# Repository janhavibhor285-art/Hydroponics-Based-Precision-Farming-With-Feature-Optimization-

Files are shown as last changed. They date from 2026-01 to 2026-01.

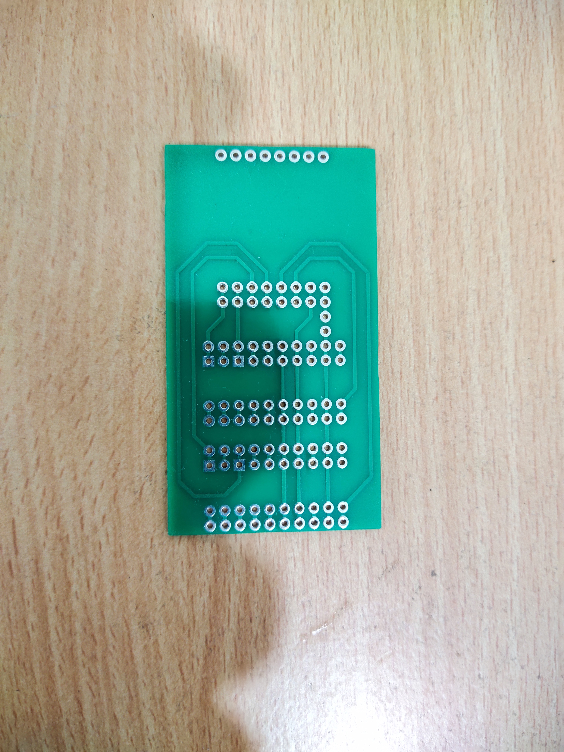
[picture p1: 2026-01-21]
2. Hardware-20260121T212549Z-1-001/2. Hardware/6. Actuator Module Final/7. Actuator Module Development/4. PCB Manufacturing Back.jpg

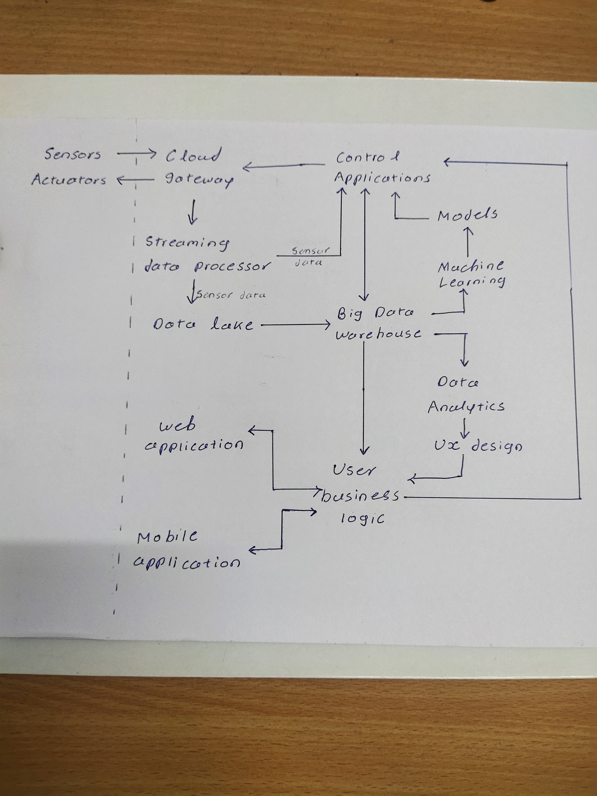
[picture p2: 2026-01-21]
8. Documentations-20260121T212609Z-1-001/8. Documentations/8. Extra Works/rough whole project architecture diagram.jpg

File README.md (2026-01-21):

# Hydroponics-Based-Precision-Farming-With-Feature-Optimization-
Author: Janhavi Bhor
Date: 22 January 2025

# Project Overview
Developed a scalable indoor hydroponics automation system with global monitoring and controllable components. Achieved 90% water savings, 51.6% power reduction, and reduced hardware costs from 1180 to 331. Operated on less than 10W, leading the project from requirement analysis to final testing.

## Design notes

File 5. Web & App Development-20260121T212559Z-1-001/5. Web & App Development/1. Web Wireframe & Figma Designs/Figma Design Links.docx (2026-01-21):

Button Design Link:

https://www.figma.com/file/rlIcAuAG75rzXwAZrkmFJh/BUTTON-DESIGN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

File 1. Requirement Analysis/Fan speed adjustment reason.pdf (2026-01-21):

Project OMEGA | @Varad Chaskar

Why adjust the fan speed instead of simply turning it ON and OFF?

Short answer: To save the power consumption

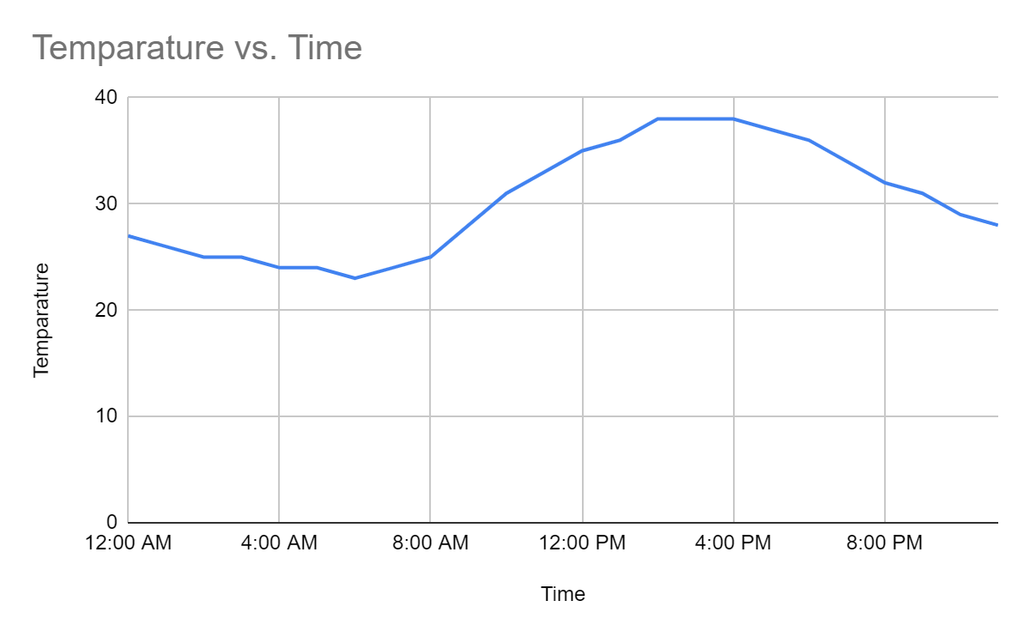
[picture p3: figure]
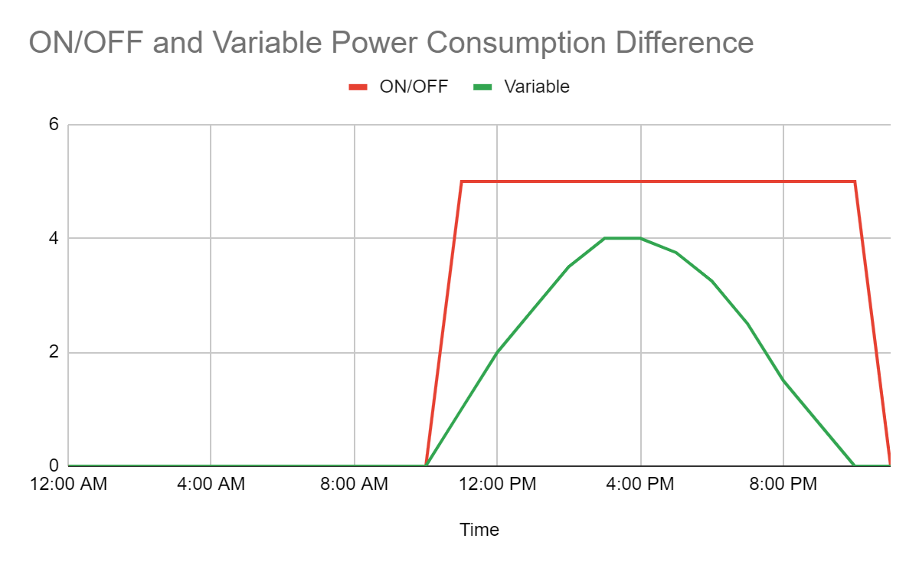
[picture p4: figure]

Assumed that the fan is taking 5V and 1A maximum current at full speed.
In the above temperature scenario, the fan remained ON for 12 Hours.
The total power consumed in ON/OFF conditions for a day in the above scenario: 60 W
The total power consumed in variable speed for a day in the above scenario: 29 W
Thus, we have saved 51.6% of the power by adjusting the fan speed according to the temperature instead of just turning it ON/OFF.

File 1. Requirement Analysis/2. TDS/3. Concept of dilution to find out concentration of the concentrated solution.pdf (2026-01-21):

### 6 ml of X ppm TDS in 1 L of water to achieve TDS of 700-800 ppm

We can use the concept of dilution. The formula for dilution is:

C1 V1 = C2 V2

Where:
C1 = initial concentration of the solution (TDS of X ppm solution)
V1 = initial volume of the solution (6 ml)
C2 = final concentration of the solution after dilution (TDS of 700-800 ppm) V2 = final volume of the solution after dilution (1 L = 1000 ml)

We want to find the initial concentration C1 (TDS of X ppm solution).

Given:
V1 = 6 ml
C2 = 750 ppm (taking an average of the range 700-800 ppm)
V2 = 1000 ml

Using the dilution formula:

C1 x V1 = C2 x V2

C1 x 6 = 750 x 1000

C1 = (750 x 1000) / 6

C1 = 125000

So, the initial concentration C1, or the TDS of the X ppm solution, is 125000 ppm.

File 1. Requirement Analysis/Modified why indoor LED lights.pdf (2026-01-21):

Project OMEGA | @Varad Chaskar

Why indoor hydroponics with LED lights rather than traditional farming?

Short answer: Because we can stack the system with LED lights and earn more profit after some years, below are the approximate cost calculations.
- Land size assumed in all comparisons: 2x1 feet
- Research on: Spinach
- The average no. of days spinach can be cultivated in a year in traditional farming: 243 (In traditional farming pests and heavy rain affect the production)
- Total number of days spinach can be cultivated in a year for hydroponics: 365
- Initial Investment in outdoor hydroponics: 3600 Rs. (Controlled Environment)
- Here, outdoor hydroponics is assumed to grow in the sunlight hence, we can’t stack it.
- Initial investment in indoor hydroponics: 6800 Rs. (2 stacks) (CE) (LED)
- One bunch of spinach can be harvested in an average of 15 days. (250-300 grams)
- Assumed cost of 1 bunch of spinach: 30 Rs.

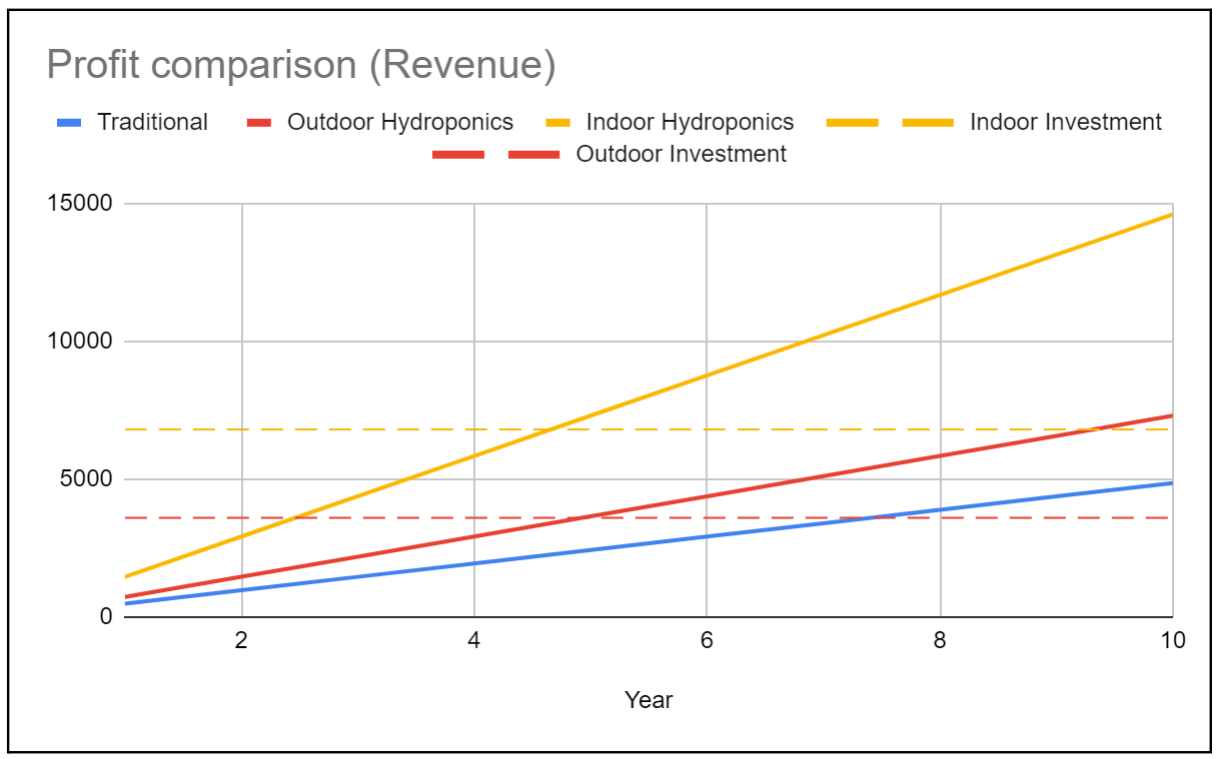
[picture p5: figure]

- Calculated total revenue of traditional farming in the year: 486 Rs.
- Calculated total revenue of outdoor hydroponics system in the year: 730 Rs.
- Calculated total revenue of indoor farming system in the year: 1460 Rs. (2 stacks)
- Years taken to be profitable in both hydroponics systems: 4.5+ Years.
- The total calculated revenue in 2x1 feet 2 stacks indoor hydroponics farming in 10 years is 14,600 Rs. and for outdoor hydroponics is 7,300 Rs.
- Note: Fertilizer cost is assumed to be the same in all methods. and the cost of pesticides in traditional farming is assumed to be the same as the electricity cost in hydroponics hence, they have not been taken into account.

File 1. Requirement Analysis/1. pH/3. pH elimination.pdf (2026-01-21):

pH elimination: using a fixed amount of nutrients with certain pH and 1 L of water.

we have 5 ml of a solute, and we want to mix it with 1 L of water with a pH of 7.0, so that the resulting pH is approximately 6.0.

We can approach this problem using the concept of dilution and the relationship between pH and the concentration of hydrogen ions ([H+]).

For dilute solutions, the pH can be approximated using the equation:

pH = -log10([H+])

Initially, the pH of the water is 7.0, which corresponds to a [H+] of 10^-7 moles/L. we want to mix in 5 ml of a solute, so the final volume becomes 1 L + 0.005 L = 1.005 L.

Let's assume the solute has an initial pH of x. After mixing, the moles of [H+] from the solute and the water must balance out to achieve a pH of 6.0:

([H+] from solute) + ([H+] from water) = Total [H+] after mixing

Using the dilution equation (C1V1 = C2V2), where C is concentration and V is volume, the [H+] from the water remains the same (10^-7), and the [H+] from the solute is given by 10^-x (since the pH of the solute is x).

So the equation becomes:

10^-x + 10^-7 = 10^-6

Solving for x:

10^-x = 10^-6 - 10^-7

x = -log10(10^-6 - 10^-7)

x ≈ 5.301

Therefore, the pH of the solute should be approximately 5.301 to achieve a resulting pH of around 6.0 after mixing it with 1 L of water with a pH of 7.0.

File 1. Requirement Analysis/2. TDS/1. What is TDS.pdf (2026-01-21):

## What is TDS? Its Importance and Maintenance in

Hydroponics.
07.05.23 11:18 PM 0 Comment(s) (https://www.citygreens.in/blogs/post/tds-and-its-importance-in-hydroponics.#comments) By City Greens (https://www.citygreens.in/blogs/author/sales-citygreens.in)

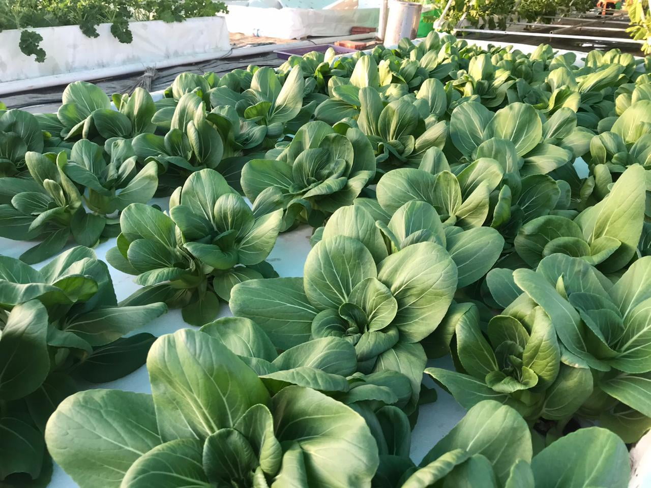
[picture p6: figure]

What is TDS?

TDS stands for Total Dissolved Solids. It is the total amount of inorganic and organic substances dissolved in water or other liquids. These dissolved substances can include minerals, salts, metals, etc. TDS is typically measured in parts per million (ppm) and is an important parameter for assessing water quality.

Why is TDS so important in hydroponics?

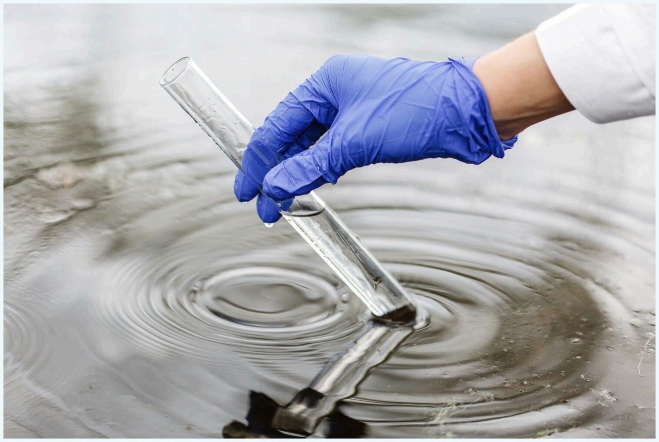
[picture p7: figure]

Water Quality Indicator

A higher TDS reading indicates a higher concentration of dissolved salts and minerals, while a lower TDS reading indicates a lower concentration.

If the raw water TDS is high it can lead to nutrient locking, which can result in poor growth and nutrient deficiencies in plants. Also, the higher the TDS, the higher the chances of the presence of harmful elements or chemicals. So it is advisable to use RO water with a lesser TDS for more control over the nutrition you provide for your plants. It is advisable to use water with a TDS of less than 250 ppm. The lower the better.

TDS Tolerance

TDS requirements for every plant are different from others. For example, lettuces and exotics need a tds range of 700-800 ppm, while tomatoes can tolerate a tds of 2100 ppm.

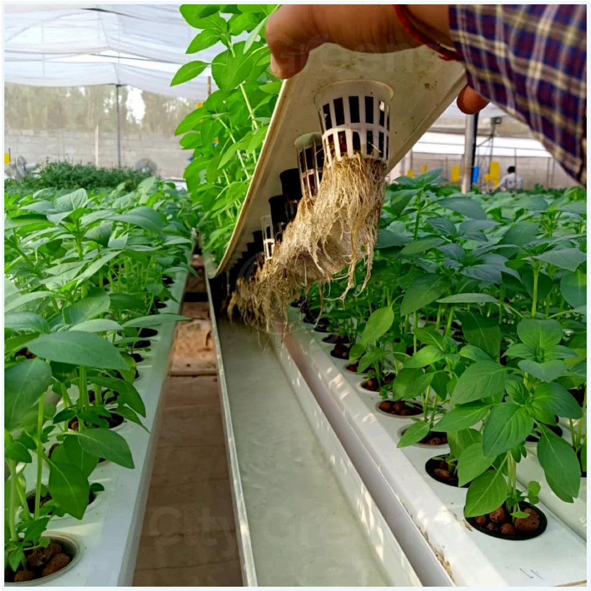
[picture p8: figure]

You can never treat lettuces and tomatoes alike and provide the same TDS levels as it can lead to nutrient burn in lettuce plants. It is very important to understand the plant's needs and provide the right TDS range as per the crops you grow. Also, note that the TDS requirement for small plants is less when you compare it with big plants.

TDS Maintenance in Hydroponics

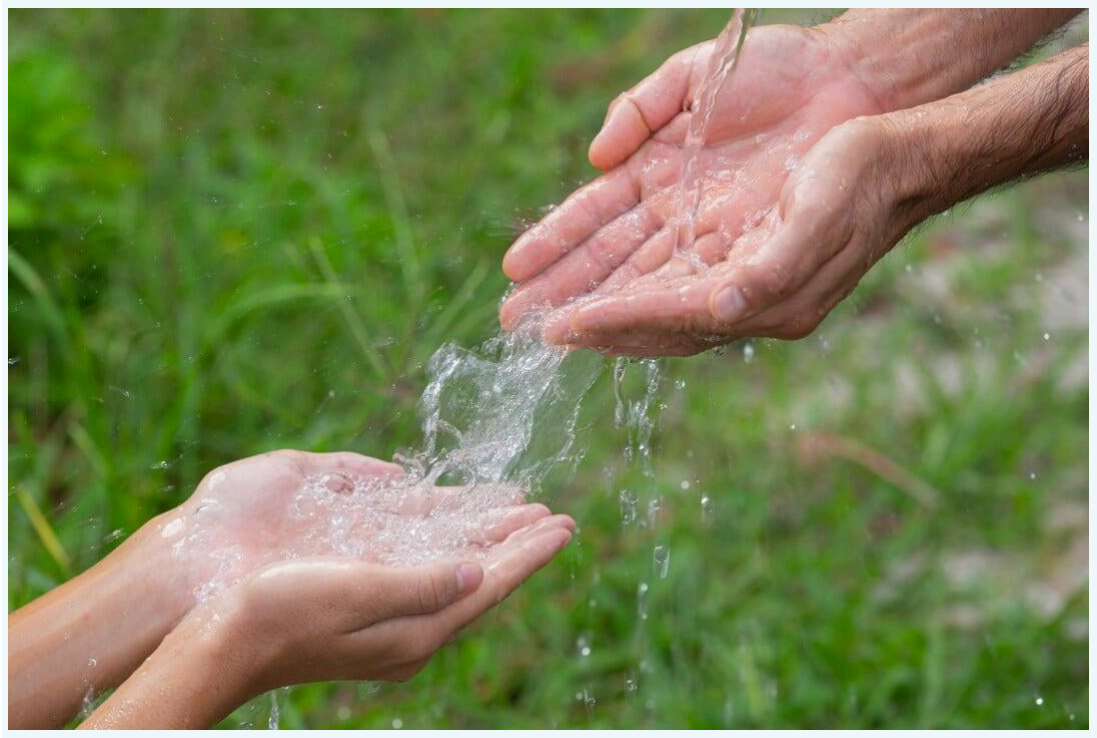
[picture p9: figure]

Start with RO Water

Reverse Osmosis (RO) water is commonly used for hydroponics as it is free of many dissolved minerals and contaminants that may be present in tap water or well water. With RO water you have better control over the nutrients you provide for your plants.

Using a Quality TDS Meter

Every action to increase or decrease the TDS depends on the reading you observe from the TDS meter. So it is crucial to use a good quality and reliable TDS meter that is clean and calibrated regularly.

Never Overdose!

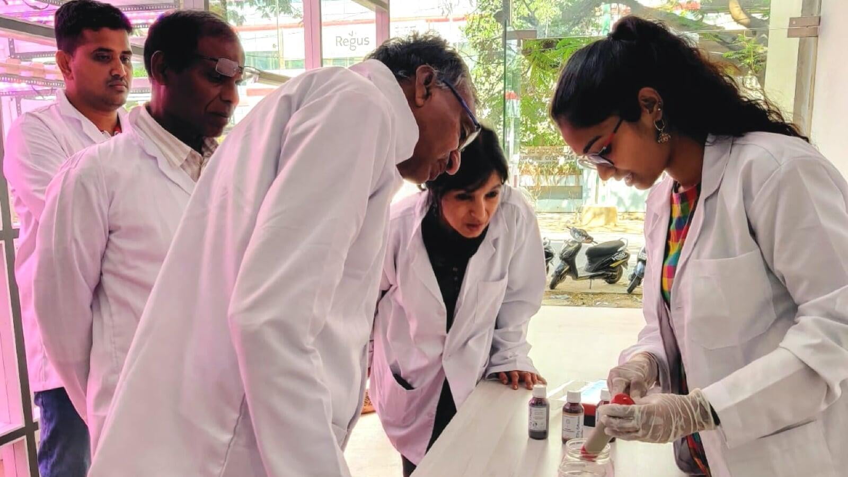
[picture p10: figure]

Overdosing nutrients in hydroponics can lead to a number of problems for your plants like nutrient burn, altered pH levels, salt buildup, and reduced plant growth.

Regular TDS Monitoring

Check the TDS of the nutrient solution at least once every day and take necessary action based on the reading. It is also important to monitor the plant's growth and check for signs of any trouble. If the leaf edges turn brown and become brittle (nutrient burn), it means the TDS is too high and we need to reduce it immediately.

In hydroponics, TDS is an essential parameter for maintaining optimal plant growth and overall system health. TDS provides information on the nutrient concentration in the water and can help you adjust nutrient levels to ensure that your plants receive the proper amount of nutrients for healthy growth. Additionally, monitoring TDS levels can provide valuable information about the quality of the water in your system, and help you identify any issues with excess minerals or contaminants. To maintain optimal TDS levels in your hydroponic system, it's important to regularly test the water with a TDS meter, adjust nutrient levels as needed, and monitor plant growth for any signs of nutrient deficiencies or imbalances.

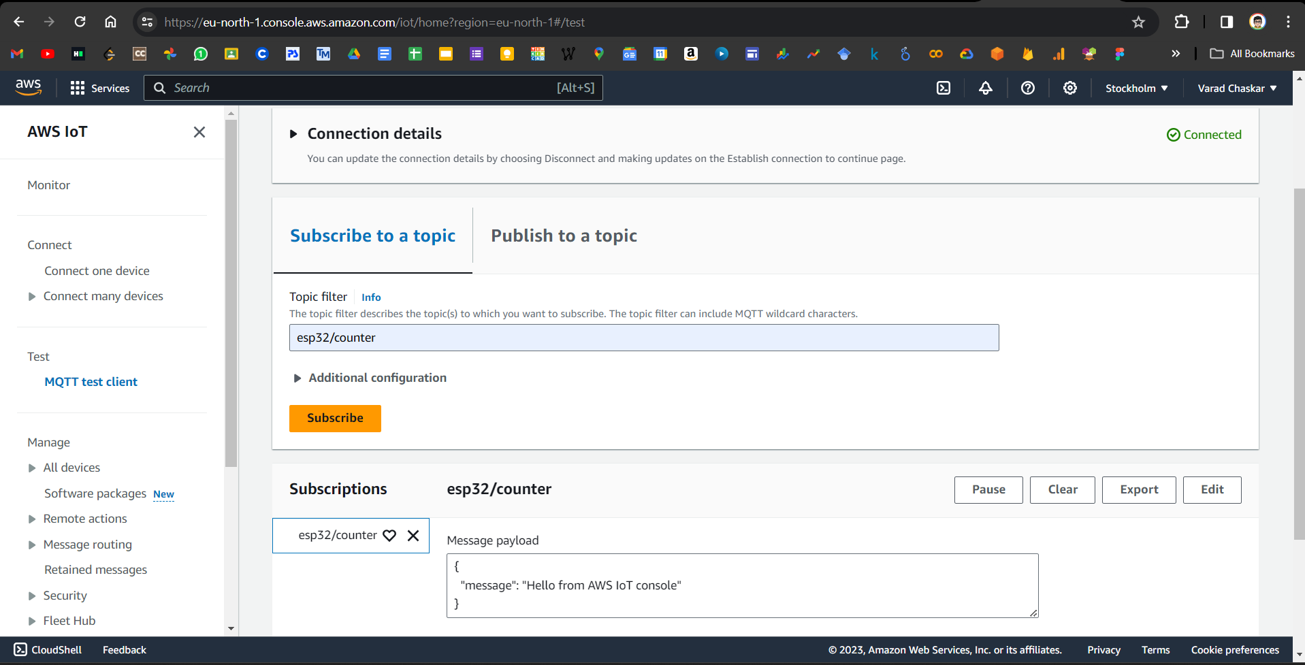
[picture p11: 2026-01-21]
4. Cloud and Enclosure Designs-20260121T212557Z-1-001/4. Cloud and Enclosure Designs/2. AWS Cloud/be 6 AWS.png

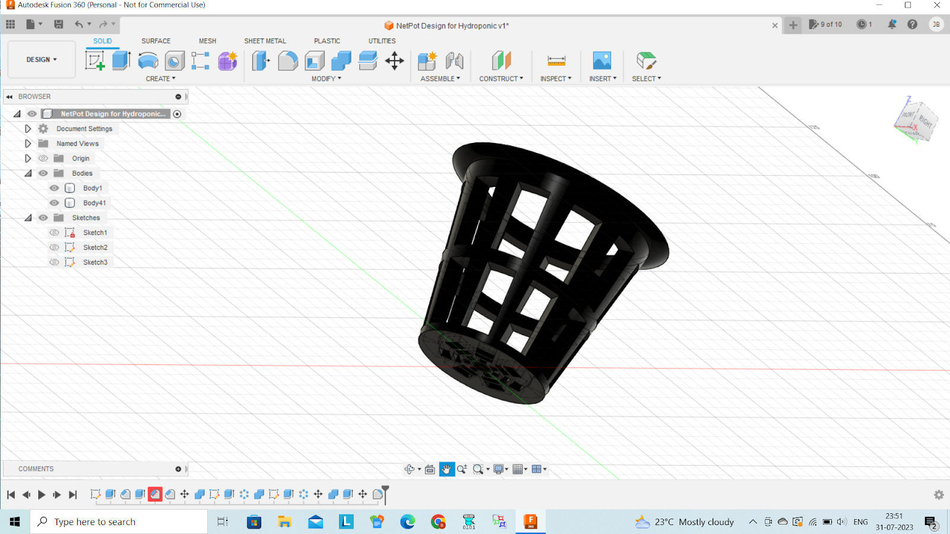
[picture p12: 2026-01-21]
4. Cloud and Enclosure Designs-20260121T212557Z-1-001/4. Cloud and Enclosure Designs/8. Enclosure Design of Netpot/Hydroponic Netpot Screenshot.png

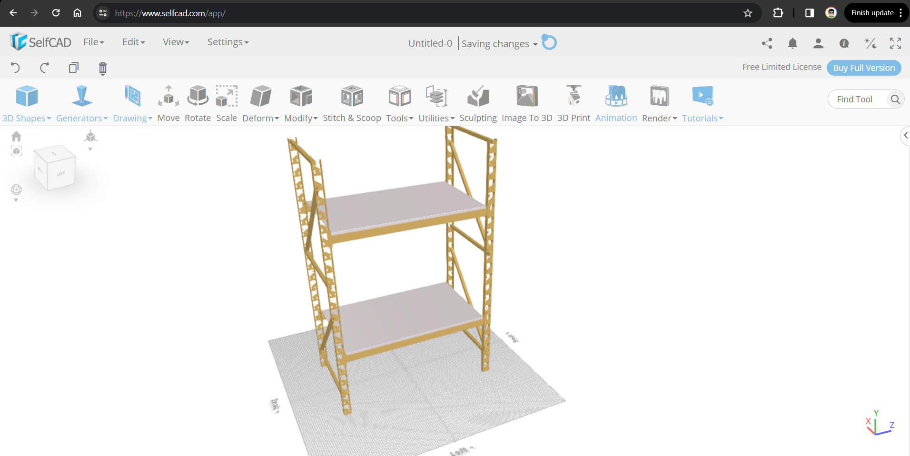
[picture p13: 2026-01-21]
4. Cloud and Enclosure Designs-20260121T212557Z-1-001/4. Cloud and Enclosure Designs/9. Enclosure Design of Stack/3D stack design on SelfCAD.png

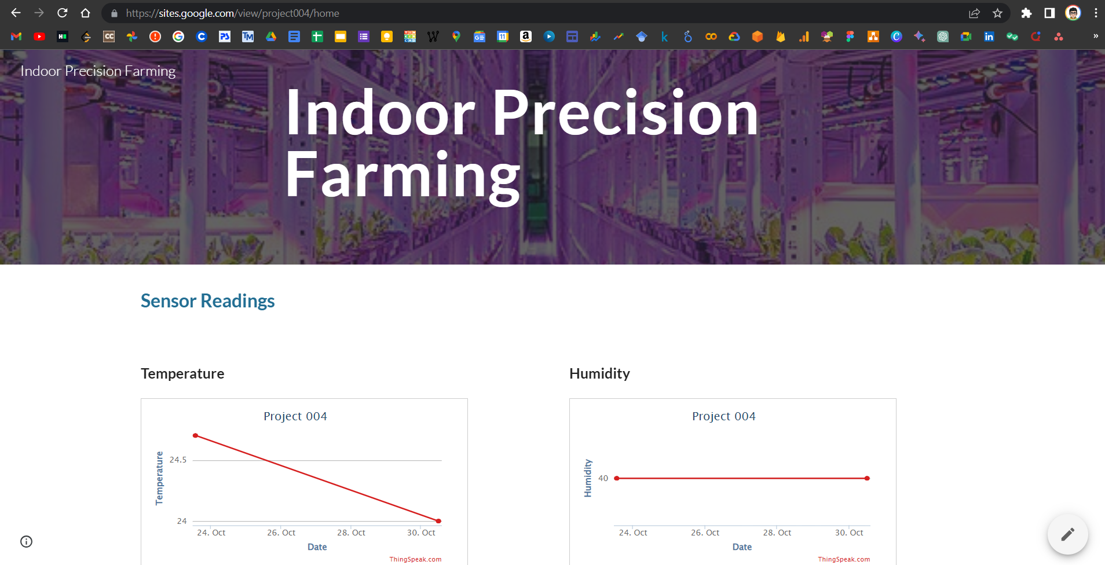
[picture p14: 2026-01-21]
2. Hardware-20260121T212549Z-1-001/2. Hardware/2. Simulations/2. Webpage of Simulation.png

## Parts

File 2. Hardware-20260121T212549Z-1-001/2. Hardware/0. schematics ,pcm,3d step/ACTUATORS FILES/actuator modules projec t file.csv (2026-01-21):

Part ID | Value | Package | Stock Code | Layer | Rotation | X | Y
U1 | L293D-007 | DIL16 |  | TOP | -90 | 986.614 | -940.551
U2 | L293D-01 | DIL16 |  | TOP | -90 | 1921.65 | -940.551
 |  | ARDUINO-SIL8 |  | TOP | -90 | 98.4252 | -940.551
 |  | SIL-100-02 |  | TOP | -180 | 345.276 | -1279.53
 |  | ARDUINO-SIL8 |  | TOP | -90 | 590.551 | -940.551
 |  | ARDUINO-SIL8 |  | TOP | -90 | 1279.53 | -938.976
 |  | ARDUINO-SIL8 |  | TOP | -90 | 1574.8 | -940.551
 |  | ARDUINO-SIL8 |  | TOP | -90 | 2263.78 | -940.551
OP1 | NSL-32SR3 | OPTO1-AXIAL |  | TOP | 0 | 917.717 | -344.882
OP2 | NSL-32SR3 | OPTO1-AXIAL |  | TOP | 0 | 1901.97 | -344.882
 |  | CON2_1X2_U_FCI |  | TOP | -270 | 590.551 | -343.701
 |  | CON2_1X2_U_FCI |  | TOP | -270 | 1574.8 | -343.701
 |  | CON2_1X2_U_FCI |  | TOP | -270 | 1279.53 | -343.701
 |  | CON2_1X2_U_FCI |  | TOP | -270 | 2263.78 | -343.701
 |  | ARDUINO-SIL8 |  | TOP | -90 | -1181.1 | -940.551
 |  | WEMOS |  | TOP | 0 | -547.441 | -940.551

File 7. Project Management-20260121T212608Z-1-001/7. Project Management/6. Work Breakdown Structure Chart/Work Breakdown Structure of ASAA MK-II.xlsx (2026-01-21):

Work Breakdown Structure
Project Name: OMEGA
Project Leader: Varad Chaskar
Requirement | Hardware | Software | Enclosure & Cloud | Web & App Develop. | AI and ML | Managenement
Document containing list | A document containing | Flowchart of the | Achitecture Diagram | Design of Web | Design of AI model | Create Project
of all requirements | Modifications summary | Sensor Module |  | Wireframe |  | Proposal
list of problems in the | Data Sheets Collection | Flowchart of the | Create 3D design of | Write code for HTML | Development of AI | Create Project
pH sensor | of the Components | Actuator Module | the Sensor Module | Slider | model | Charter
List of problems present | Breadboard Design of | Code for the | Create 3D design of | Write code for HTML | Performance parameter | Create Work Breakdown
in the nutrient sensor | the Sensor Module | Sensor Module | the Actuator Module | Button | plotting | Structure Chart
Collection of news | Breadboard Design of | Code for the |  | Documentation of | Evaulation of AI | Create and maintain
articles for advantages | the Actuator Module | Actuator Module | the UPS module | Adjustable Slider | model | meeting minutes
Why hydroponic | Breadboard Design of | Documentation of code |  | Documentation of | Deployment and | Create and maintain
automation fails? | the UPS Module | for Sensor Module | hydroponic tank | Button | integration to web | GANTT chart
Nutrient required for | Schematic Design of | Documentation of code |  | List of all features of | Screenshots of | Create Expense Reports
plant according growth | the Sensor Module | for Actuator Module | netpot | Webpage | AI Model
Need and difference with | Schematic Design of | Testing Plans for | Screenshots of AWS | Screenshots of |  | Screenshots of Asana
UV light | the Actuator Module | both Modules | cloud and Thingspeak | Webpage
Need and difference with | PCB Design of the | Test cases of the
air pump | Sensor Module | Sensor Module
 | PCB Design of the | Test cases for the
 | Actuator Module | Actuator Module
 | Make Component list of
 | the Sensor Module
 | Make Component list of
 | the Actuator Module
 | Create Bill of Materials
 | of whole project

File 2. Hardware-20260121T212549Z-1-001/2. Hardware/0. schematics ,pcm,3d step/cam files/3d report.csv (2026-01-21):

Part ID | Value | Package | Stock Code | Layer | Rotation | X | Y
ESP 32 CAM | DFR0602 | DFR0602 |  | TOP | 0 | -1715.35 | 2701.18
USB 01 | AU-Y1005-R | CON4_1X4_USB_AM | Digikey AE9923-ND | TOP | -270 | -3112.11 | 2716.54
D-P-CO | 26630401RP2 | CON4_1X4_HDR_2663 | NorComp 26630401RP2 | TOP | -270 | -2559.06 | 3287.4
PG-CO | 26630201RP2 | CON2_1X2_HDR_2663 | NorComp 26630201RP2 | TOP | -90 | -688.976 | 2598.43

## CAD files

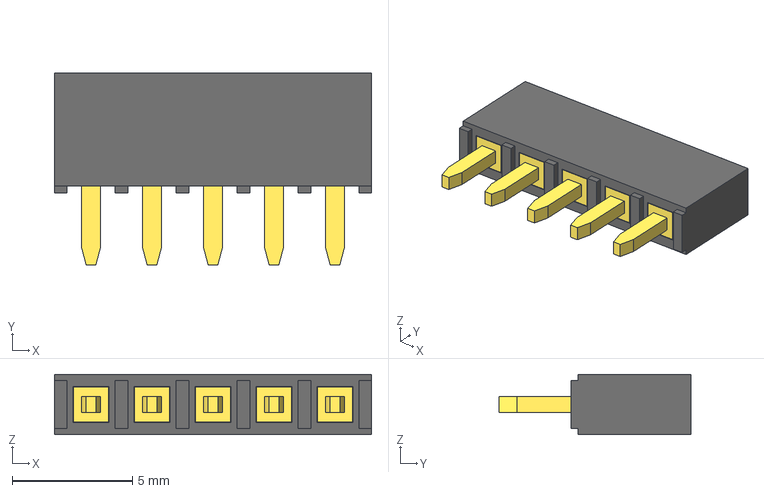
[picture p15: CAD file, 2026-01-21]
2. Hardware-20260121T212549Z-1-001/2. Hardware/0. schematics ,pcm,3d step/ACTUATORS FILES/pin-header-female-2-54mm-different-pin-numbers-1.snapshot.4/5-Pin Header - Female - 2.54mm.step
13.2 x 8.00 x 2.50 mm

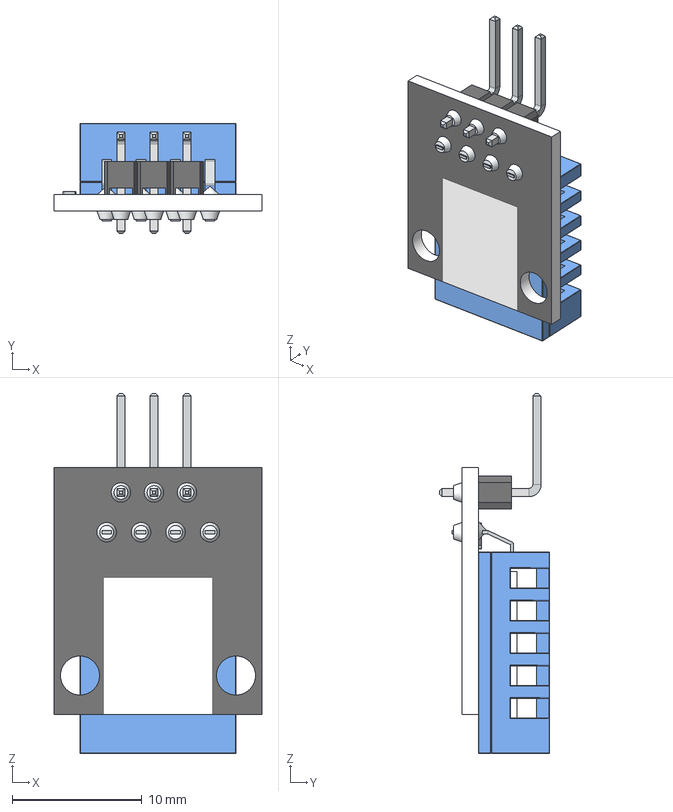
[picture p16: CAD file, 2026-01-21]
2. Hardware-20260121T212549Z-1-001/2. Hardware/0. schematics ,pcm,3d step/sensor module files/schematic,pcb,3d step/3d files/ky-015-dht11-1.snapshot.1/KY-015.step
16.0 x 8.50 x 27.7 mm

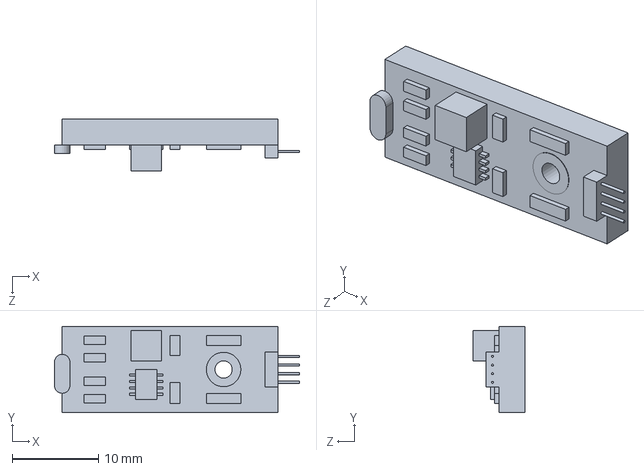
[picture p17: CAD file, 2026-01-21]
2. Hardware-20260121T212549Z-1-001/2. Hardware/0. schematics ,pcm,3d step/sensor module files/schematic,pcb,3d step/3d files/ldr-arduino-module-1.snapshot.2/LDR.SLDPRT
28.4 x 10.0 x 6.00 mm

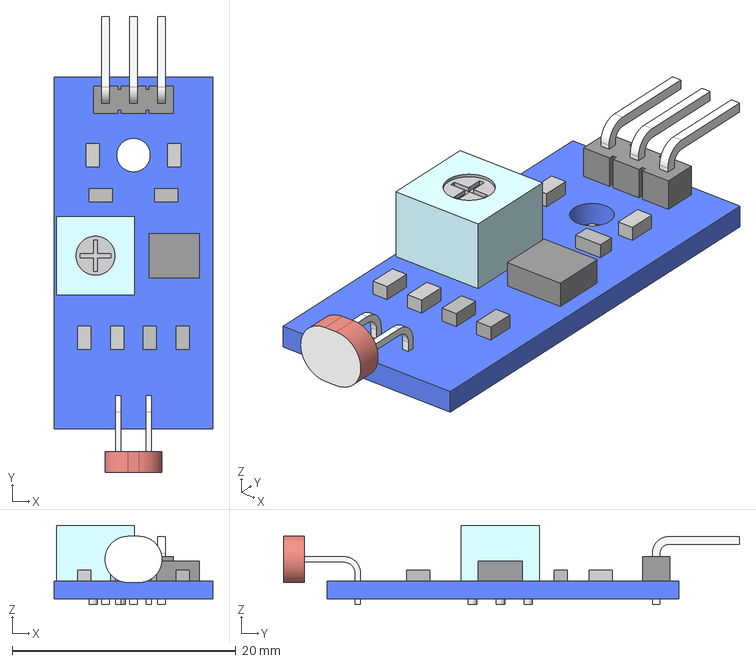
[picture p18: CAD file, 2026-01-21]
2. Hardware-20260121T212549Z-1-001/2. Hardware/0. schematics ,pcm,3d step/sensor module files/schematic,pcb,3d step/3d files/light-sensor-ldr-1.snapshot.2/Light sensor LDR v1.step
14.2 x 40.8 x 7.10 mm

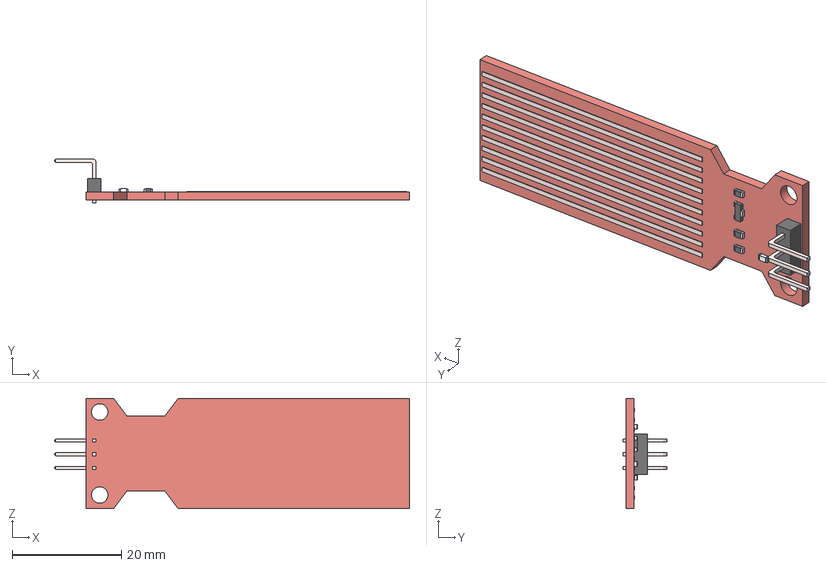
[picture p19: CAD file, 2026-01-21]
2. Hardware-20260121T212549Z-1-001/2. Hardware/0. schematics ,pcm,3d step/sensor module files/schematic,pcb,3d step/3d files/water-level-sensor-1.snapshot.4/Capteur Pluie2 v3.step
65.0 x 8.00 x 20.2 mm

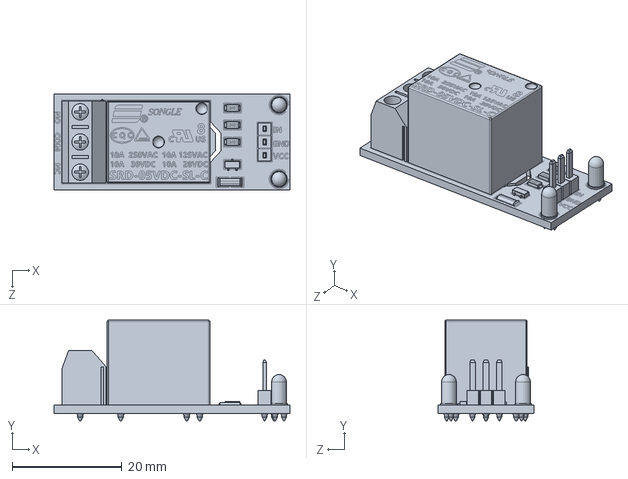
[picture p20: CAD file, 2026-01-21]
2. Hardware-20260121T212549Z-1-001/2. Hardware/0. schematics ,pcm,3d step/ups module files/1-channel-relay-module-1.snapshot.6/Arduino relay 01.SLDPRT
43.0 x 18.4 x 17.5 mm

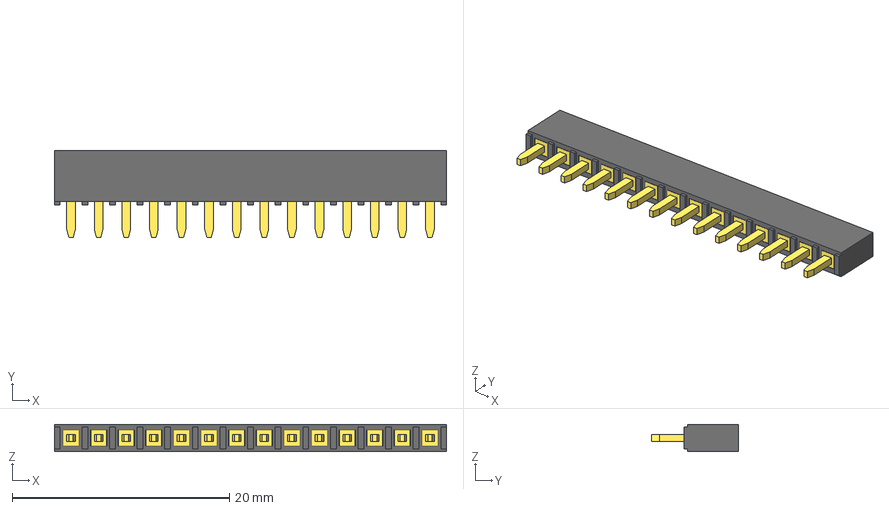
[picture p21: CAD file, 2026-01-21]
2. Hardware-20260121T212549Z-1-001/2. Hardware/0. schematics ,pcm,3d step/ACTUATORS FILES/pin-header-female-2-54mm-different-pin-numbers-1.snapshot.4/14-Pin Header - Female - 2.54mm.step
36.1 x 8.00 x 2.50 mm

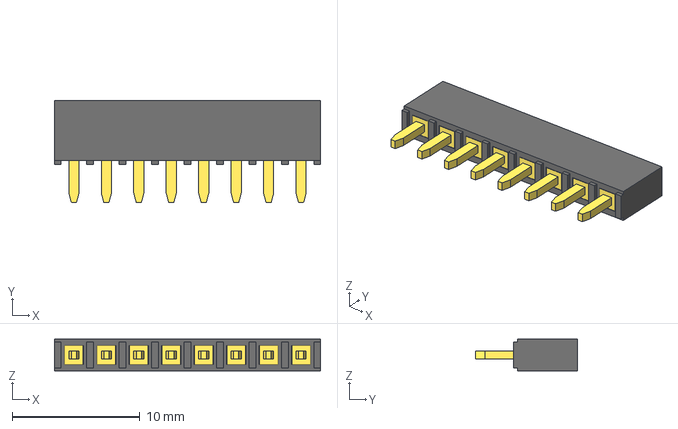
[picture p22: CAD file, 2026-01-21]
2. Hardware-20260121T212549Z-1-001/2. Hardware/0. schematics ,pcm,3d step/ACTUATORS FILES/pin-header-female-2-54mm-different-pin-numbers-1.snapshot.4/8-Pin Header - Female - 2.54mm.step
20.8 x 8.00 x 2.50 mm

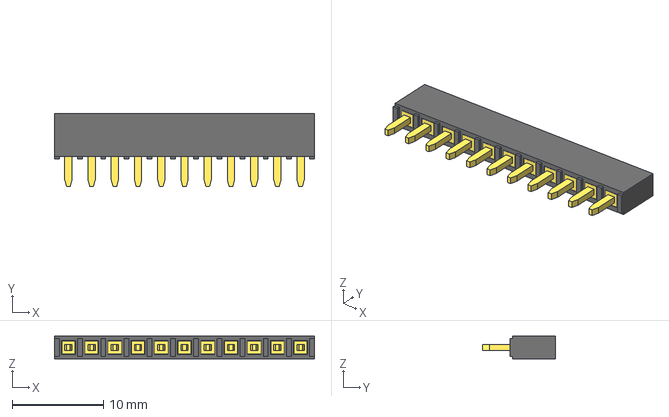
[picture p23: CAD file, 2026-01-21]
2. Hardware-20260121T212549Z-1-001/2. Hardware/0. schematics ,pcm,3d step/ACTUATORS FILES/pin-header-female-2-54mm-different-pin-numbers-1.snapshot.4/11-Pin Header - Female - 2.54mm.step
28.4 x 8.00 x 2.50 mm

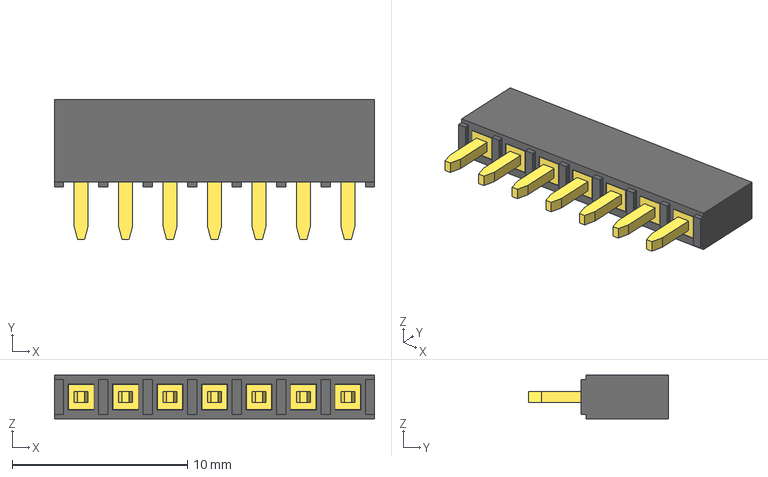
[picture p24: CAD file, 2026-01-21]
2. Hardware-20260121T212549Z-1-001/2. Hardware/0. schematics ,pcm,3d step/ACTUATORS FILES/pin-header-female-2-54mm-different-pin-numbers-1.snapshot.4/7-Pin Header - Female - 2.54mm.step
18.3 x 8.00 x 2.50 mm

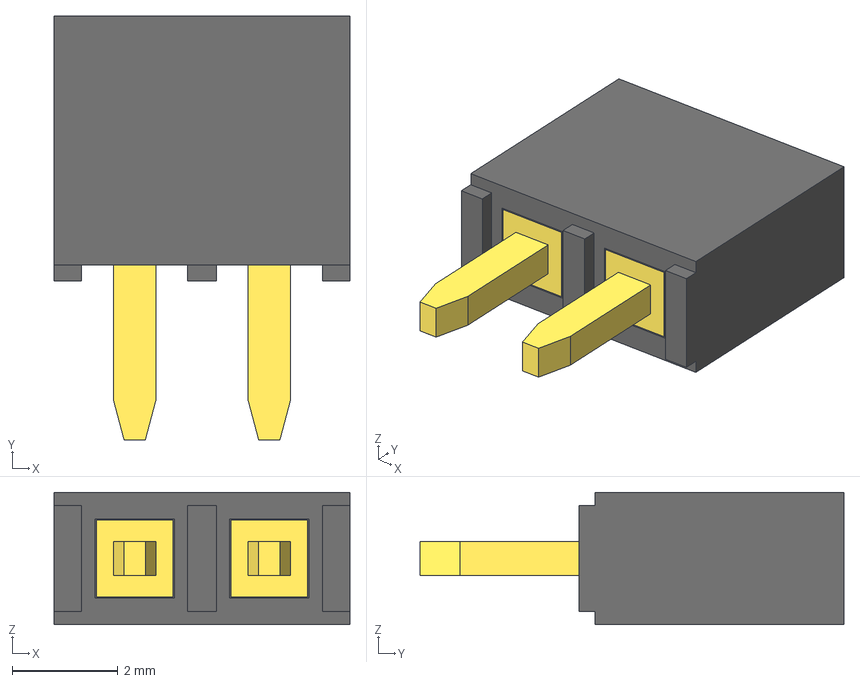
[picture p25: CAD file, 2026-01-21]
2. Hardware-20260121T212549Z-1-001/2. Hardware/0. schematics ,pcm,3d step/ACTUATORS FILES/pin-header-female-2-54mm-different-pin-numbers-1.snapshot.4/2-Pin Header - Female - 2.54mm.step
5.58 x 8.00 x 2.50 mm

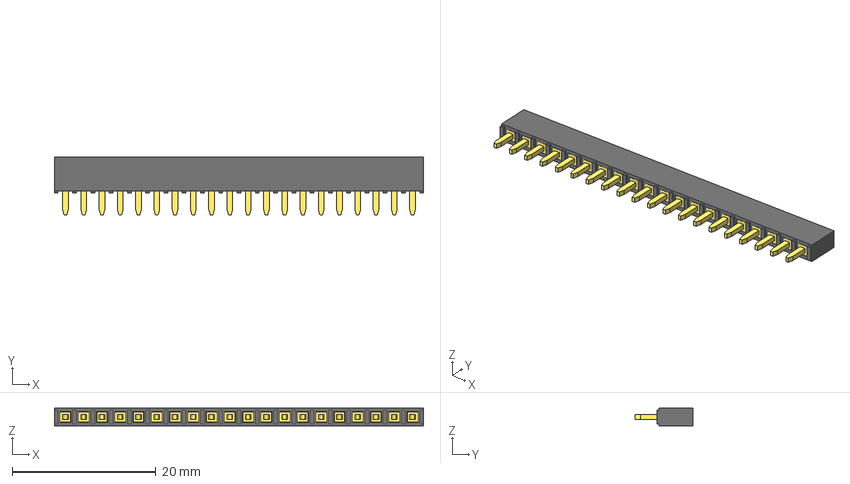
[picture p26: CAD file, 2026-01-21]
2. Hardware-20260121T212549Z-1-001/2. Hardware/0. schematics ,pcm,3d step/ACTUATORS FILES/pin-header-female-2-54mm-different-pin-numbers-1.snapshot.4/20-Pin Header - Female - 2.54mm.step
51.3 x 8.00 x 2.50 mm

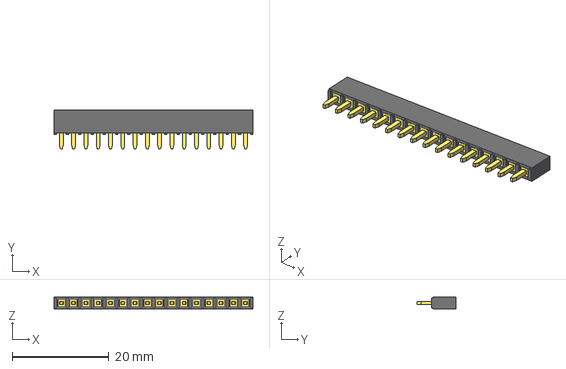
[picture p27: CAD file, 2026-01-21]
2. Hardware-20260121T212549Z-1-001/2. Hardware/0. schematics ,pcm,3d step/ACTUATORS FILES/pin-header-female-2-54mm-different-pin-numbers-1.snapshot.4/16-Pin Header - Female - 2.54mm.step
41.1 x 8.00 x 2.50 mm

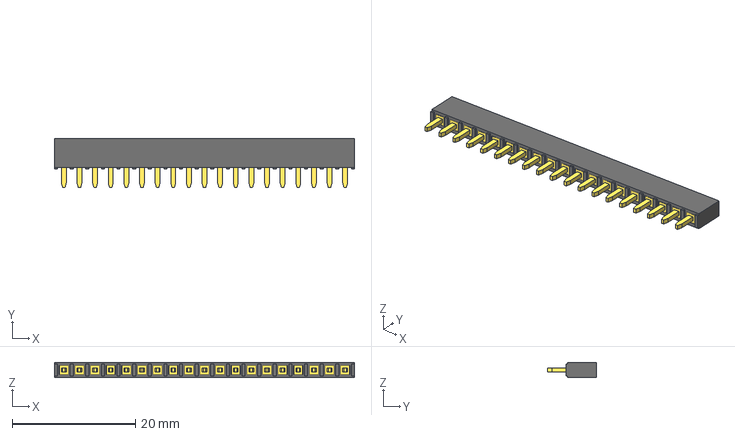
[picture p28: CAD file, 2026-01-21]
2. Hardware-20260121T212549Z-1-001/2. Hardware/0. schematics ,pcm,3d step/ACTUATORS FILES/pin-header-female-2-54mm-different-pin-numbers-1.snapshot.4/19-Pin Header - Female - 2.54mm.step
48.8 x 8.00 x 2.50 mm

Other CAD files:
2. Hardware-20260121T212549Z-1-001/2. Hardware/0. schematics ,pcm,3d step/ACTUATORS FILES/pin-header-female-2-54mm-different-pin-numbers-1.snapshot.4/13-Pin Header - Female - 2.54mm.step
2. Hardware-20260121T212549Z-1-001/2. Hardware/0. schematics ,pcm,3d step/ACTUATORS FILES/pin-header-female-2-54mm-different-pin-numbers-1.snapshot.4/18-Pin Header - Female - 2.54mm.step
2. Hardware-20260121T212549Z-1-001/2. Hardware/0. schematics ,pcm,3d step/ACTUATORS FILES/pin-header-female-2-54mm-different-pin-numbers-1.snapshot.4/10-Pin Header - Female - 2.54mm.step
2. Hardware-20260121T212549Z-1-001/2. Hardware/0. schematics ,pcm,3d step/ACTUATORS FILES/pin-header-female-2-54mm-different-pin-numbers-1.snapshot.4/12-Pin Header - Female - 2.54mm.step
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

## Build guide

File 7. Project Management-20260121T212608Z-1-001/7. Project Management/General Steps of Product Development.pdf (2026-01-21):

### General Steps of Product Development

- Varad Chaskar

### 1. User Research:

Conduct user research to understand the target audience, their needs, behaviors, and goals. Gather qualitative and quantitative data through interviews, surveys, and user observations. Create user personas and user stories to represent different user types and their motivations.

### 2. User Requirements Gathering:

Collaborate with stakeholders to define project goals, objectives, and requirements. Identify business goals, user needs, and project constraints. Align user requirements with business objectives.

### 3. Define the Project Scope:

Clearly define the objectives and requirements of the electronic project. Understand the purpose, functionality, performance, and constraints of the project.

### 4. Product Research and Planning:

Conduct thorough research on similar projects and available technologies. Plan the project timeline, allocate resources, and identify the necessary components and tools.

### 5. Define the Product Requirements:

Determine the purpose, specifications, and functionalities of the hardware. Consider factors such as performance, power consumption, size, and cost.

### 6. Design the Product Circuit:

Based on your project requirements, design the circuit diagram. Determine the necessary components, their connections, and their values. Use software tools like circuit design software or simulation tools to assist in designing and validating the circuit.

### 7. Select and Procure Electronic Components:

Identify the components needed for your circuit design. Create a bill of materials (BOM) listing all the necessary components. Procure the components from reliable suppliers or vendors.

### 8. Prototype the Electronic Circuit:

Build a prototype of your circuit using a breadboard or a prototyping board. Assemble the components according to the circuit design. Double-check the connections to ensure they match the circuit diagram.

### 9. Basic Electronic Test and Debug:

Power up the circuit and test its functionality. Use appropriate test equipment, such as a multimeter or an oscilloscope, to measure voltages, currents, and signals at different points in the circuit. Debug any issues or errors and make necessary adjustments to the circuit.

### 10. Software System Design:

Create a high-level system design that outlines the architecture, modules, and components of the software. Determine how different parts of the system will interact and communicate. Design the database schema and plan the user interface.

### 11. Software Detailed Design:

Break down the system design into detailed components and modules. Specify the interfaces, data structures, algorithms, and functionality of each module. Design the user interface, wireframes, and mockups to depict the visual representation of the software.

### 12. Software Implementation:

Write code and develop the software based on the detailed design. Use appropriate programming languages, frameworks, and tools. Follow coding standards and best practices to ensure readability, maintainability, and efficiency. Create unit tests to verify the functionality of individual components.

### 13. Identify the IoT platform:

Select an appropriate IoT platform that aligns with your project requirements. Consider factors such as device compatibility, cloud integration, data management, security, scalability, and analytics capabilities.

### 14. Design the IoT System Architecture:

Define the overall system architecture for your IoT project. Determine how the devices/sensors will communicate with each other and the cloud platform. Consider protocols like MQTT or HTTP, and choose between centralized or decentralized architectures.

### 15. Select and connect IoT devices:

Choose the appropriate IoT devices or sensors for your project based on the data you need to collect. Ensure compatibility with your chosen IoT platform. Connect the devices to the network (Wi-Fi, Ethernet, Bluetooth, LoRaWAN, etc.) and establish the necessary configurations.

### 16. Develop IoT Firmware/Software:

Depending on your project, you may need to develop firmware or software to control the IoT devices, collect sensor data, and handle communication with the IoT platform. Use suitable programming languages and frameworks based on the device and platform requirements.

### 17. Implement data collection and storage:

Set up data collection mechanisms to capture data from the connected devices/sensors. Define the data formats, frequency, and protocols for data transmission. Store the collected data in a reliable and scalable manner, either locally or in the cloud.

### 18. Implement data processing and analytics:

Process and analyze the collected data to extract meaningful insights. Use appropriate algorithms, machine learning techniques, or data processing tools to derive actionable information from the data. Visualize the data using charts, graphs, or dashboards for better understanding.

### 19. Gather and preprocess data:

Collect the relevant data required for training and evaluation. Clean the data by removing any inconsistencies, missing values, or outliers. Perform preprocessing steps like normalization, feature scaling, or dimensionality reduction as needed.

### 20. Split the data:

Divide the dataset into training, validation, and test sets. The training set is used to train the model, the validation set is used to fine-tune hyperparameters and evaluate model performance, and the test set is used to assess the final model's generalization.

### 21. Select a suitable ML algorithm:

Choose an appropriate machine learning algorithm that aligns with your problem and data characteristics. Consider factors such as the nature of the data (classification, regression, clustering, etc.), size of the dataset, interpretability requirements, and computational resources.

### 22. Design the ML model architecture:

Define the structure and parameters of the chosen algorithm. This step involves selecting the number of layers, neurons, activation functions, loss functions, and optimization algorithms for neural networks. For other algorithms, define the specific settings and parameters.

### 23. Train the ML model:

Use the training data to train the model by feeding it with input features and their corresponding target outputs. The model learns patterns and relationships present in the training data through an iterative process known as optimization or gradient descent.

### 24. Evaluate and fine-tune the ML model:

Assess the model's performance using the validation set. Measure metrics such as accuracy, precision, recall, F1 score, or mean squared error, depending on the problem type. Adjust hyperparameters, modify the model architecture, or employ regularization techniques to improve the model's performance.

### 25. Test the ML model:

Once you're satisfied with the model's performance, evaluate it using the test set, which represents unseen data. Measure its performance and compare it to the validation results to ensure there is no overfitting.

### 26. Deploy the ML model:

If the model meets the desired performance criteria, deploy it into the production environment. This step involves integrating the model into the target system, making predictions on new data, and monitoring its performance in real-world scenarios.

### 27. Monitor and update ML model:

Continuously monitor the model's performance in the production environment. Collect feedback, track metrics, and retrain or update the model periodically to adapt to changing data patterns or to improve its performance over time.

### 28. Implement real-time monitoring and control of IoT devices:

Set up mechanisms to monitor the IoT devices and receive real-time notifications or alerts in case of anomalies or predefined events. Implement control mechanisms to remotely operate or configure the IoT devices if necessary.

### 29. Implement IoT security measures:

Incorporate security measures to protect the IoT devices, data, and the overall system. Consider authentication, encryption, access control, and intrusion detection mechanisms to safeguard against unauthorized access and data breaches.

### 30. Map UI User Flows and Information Architecture:

Map out user flows, task flows, and user journeys. Create a site map or flow diagram to visualize the structure and organization of content. Ensure intuitive navigation and logical information hierarchy.

### 31. Wireframing and Prototyping UI:

Create low-fidelity wireframes to outline the basic layout and structure of the user interface. Focus on content placement, functionality, and interaction without visual details. Develop interactive prototypes to simulate user interactions and test the flow and usability of the design.

### 32. UI Visual Design:

Develop the visual elements of the user interface, including colors, typography, icons, and imagery. Align the visual design with the brand identity and user preferences. Create a consistent and visually appealing design that enhances the user experience.

### 33. UI Interaction Design:

Design the interactions and behaviors of the user interface elements. Define how users will navigate, interact, and accomplish tasks within the interface. Ensure intuitive and responsive interactions to enhance usability and engagement.

### 34. UX Usability Testing:

Conduct usability tests with real users to evaluate the effectiveness and ease of use of the user interface. Gather feedback on the design, identify pain points, and test the usability of the interface. Iterate and refine the design based on user feedback and observations.

### 35. UX Iterative Design:

Iterate on the design based on user feedback, usability test results, and stakeholder input. Continuously refine and improve the user interface based on user needs and goals. Test and validate design decisions throughout the iterative process.

### 36. UX Accessibility and Inclusivity:

Ensure the user interface design is accessible to users with disabilities. Follow accessibility guidelines and standards to make the design inclusive and usable for all users. Consider factors such as color contrast, screen reader compatibility, and keyboard navigation.

### 37. UX Collaboration with Development Team:

Collaborate closely with the development team to ensure the design is implemented accurately. Provide design assets, documentation, and guidance to developers during the implementation phase. Maintain open communication and address any design or implementation challenges.

### 38. UI/UX Design Documentation:

Document the UX/UI design specifications, guidelines, and standards. Create style guides or design systems to ensure consistency across the user interface. Provide detailed design documentation for developers, stakeholders, and future reference.

### 39. User Interface Review:

Conduct a final review of the implemented user interface to ensure it aligns with the design vision and meets the usability and functionality requirements. Perform a thorough review of the design to ensure consistency, responsiveness, and visual appeal.

### 40. User Interface Design to IoT:

Design a user-friendly interface for users to interact with the IoT product. Consider mobile apps, web interfaces, or command-line interfaces based on the project requirements. Focus on providing intuitive control, monitoring, and visualization of IoT device data.

### 41. Test and validate IoT system:

Thoroughly test the IoT system to ensure its functionality, reliability, and performance. Validate the system against the defined requirements and use cases. Perform integration testing, stress testing, and security testing to identify and address any issues or vulnerabilities.

### 42. Fabricate the PCB (Printed Circuit Board):

Once you're satisfied with the prototype, you can move to the next stage of creating a custom PCB. Design the PCB layout using PCB design software, taking into account the component placement, routing, and signal integrity considerations. Generate the Gerber files required for PCB fabrication.

### 43. PCB fabrication and assembly:

Send the Gerber files to a PCB manufacturer or use DIY methods to fabricate the PCB. Once the PCBs are ready, solder the components onto the PCB following proper soldering techniques. Ensure all connections are secure and free from solder bridges or other soldering defects.

### 44. Final Firmware/Software Development:

Develop the firmware or software necessary to control and operate the hardware. This could involve programming microcontrollers or other embedded systems, developing device drivers, or creating user interfaces.

### 45. Final Software Testing and Debugging:

Perform thorough testing of the hardware to ensure it meets the specified requirements. This includes functional testing, performance testing, and compatibility testing. Identify and resolve any issues or bugs that arise during the testing phase.

### 46. Test the final product:

Power up the completed PCB and test its functionality and performance. Verify that all the components are working correctly, and the circuit is functioning as intended. Perform any necessary adjustments or troubleshooting if issues are detected.

### 47. Enclosure design and integration:

If required, design or select an appropriate enclosure for your electronics project. Consider factors such as size, aesthetics, ventilation, and user interface. Integrate the PCB and other components into the enclosure, ensuring proper mechanical support, secure connections, and accessibility for maintenance or future upgrades. Consider factors such as aesthetics, protection, cooling, and user accessibility.

### 48. Documentation and final touches:

Document the project by creating detailed schematics, assembly instructions, user manuals, and any other relevant documentation. Include proper labeling and markings on the PCB and the enclosure. Organize and package the project neatly, ensuring it is presentable and easy to understand for others.

### 49. Certification and Compliance:

If applicable, ensure that the hardware complies with relevant industry standards and regulations. This may involve obtaining certifications such as CE, FCC, or UL, depending on the target market.

### 50. Manufacturing and Production:

Once the design is finalized and all testing and compliance requirements are met, initiate the production process. This may involve outsourcing manufacturing to a third-party or setting up an in-house production line.

### 51. Quality Control:

Implement quality control measures throughout the manufacturing process to ensure consistent and reliable hardware. Perform inspections, testing, and verification at various stages of production.

### 52. Packaging and Distribution:

Package the finished hardware and prepare it for distribution or sale. This includes labeling, documentation, and appropriate packaging materials to protect the hardware during transportation.

### 53. Maintenance and Support:

Provide ongoing support, maintenance, and updates for the hardware as needed. This may involve releasing firmware or software updates, addressing customer inquiries or issues, and providing documentation or training materials.

It's important to note that building hardware can be a complex and iterative process. Design revisions, additional testing, and improvements are often required to refine the product and ensure its functionality, reliability, and user satisfaction.

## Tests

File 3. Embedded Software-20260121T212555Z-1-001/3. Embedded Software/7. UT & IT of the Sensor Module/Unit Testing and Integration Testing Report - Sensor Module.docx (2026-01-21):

Unit Testing and Integration Testing Report - Sensor Module

Author: Varad Chaskar

Date: January 28, 2024

Unit Test:

Test Case | Description | Expected Result | Actual Result | Pass/Fail
UT-001 | Verify successful initialization of WiFiManager | WiFiManager connects successfully to WiFi | Connected to WiFi | Pass
UT-002 | Check DHT sensor initialization | DHT sensor is initialized without errors | Sensor initialized without errors | Pass
UT-003 | Read temperature from DHT sensor | Temperature reading within expected range | 25.5°C | Pass
UT-004 | Read humidity from DHT sensor | Humidity reading within expected range | 55% | Pass
UT-005 | Read analog input from LDR | Analog value is read successfully | 450 | Pass
UT-006 | Read the water level from ThingSpeak | Water level reading retrieved successfully | 1 | Pass
UT-007 | Write temperature data to ThingSpeak | Temperature data successfully written to ThingSpeak | Data written successfully | Pass
UT-008 | Write humidity data to ThingSpeak | Humidity data successfully written to ThingSpeak | Data written successfully | Pass
UT-009 | Write LDR value to ThingSpeak | LDR value successfully written to ThingSpeak | Data written successfully | Pass
UT-010 | Write water level data to ThingSpeak | Water level data successfully written to ThingSpeak | Data written successfully | Pass

Integration Test:

Test Case | Description | Expected Result | Actual Result | Pass/Fail
IT-001 | Ensure WiFi connection and ThingSpeak initialization | WiFi connection and ThingSpeak initialization successful | Connected to WiFi and ThingSpeak initialized successfully | Pass
IT-002 | Verify seamless data transmission to ThingSpeak | Data is transmitted to ThingSpeak without errors | Data transmitted without errors | Pass
IT-003 | Check correct execution of loop() function | Loop function executes without errors | Loop function executed successfully | Pass

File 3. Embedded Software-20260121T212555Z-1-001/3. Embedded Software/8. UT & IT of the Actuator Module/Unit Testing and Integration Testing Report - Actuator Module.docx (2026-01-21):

Unit Testing and Integration Testing Report - Actuator Module

Author: Varad Chaskar

Date: January 28, 2024

Introduction:

This document presents the results of unit testing conducted on the Actuator Module code. The purpose of this testing is to verify the correctness and reliability of individual components within the codebase. The unit tests focus on specific functions, methods, and modules to ensure their functionality aligns with the intended design.

Integration Testing ensures that individual software components seamlessly work together cohesively within the complete system. This phase validates interactions between modules, aiming to detect and address any issues arising from the integration of diverse components, ensuring a robust and reliable software product.

Unit Test:

Test Case | Description | Expected Result | Actual Result | Pass/Fail
1 | Verify WiFiManager setup | WiFiManager initializes successfully | Initialization successful | Pass
2 | Check the initialization of ThingSpeak | ThingSpeak client initialized without errors | Initialization without errors | Pass
3 | Test WiFi connection | Successfully connect to the WiFi network | Connected to WiFi | Pass
4 | Verify GPIO pin modes | Ensure correct initialization of GPIO pins | GPIO pins initialized correctly | Pass
5 | Check LED control logic | Validate the control logic for LEDs based on ThingSpeak data | LED control logic functioning as expected | Pass

Integration Test:

Test Case | Description | Expected Result | Actual Result | Pass/Fail
1 | Verify end-to-end functionality | Actuator Module successfully connects to WiFi, reads ThingSpeak data, and controls actuators accordingly | All steps completed successfully | Pass
2 | Test error handling | Simulate WiFi connection failure and ensure proper error handling and recovery | WiFi connection failure handled, and recovery successful | Pass
3 | Check for correct ThingSpeak integration | Confirm that the Actuator Module reads data from the specified ThingSpeak fields and performs the expected actions | Data read from ThingSpeak and actuators controlled correctly | Pass
4 | Validate actuation scenarios | Test various scenarios for actuation based on different values of ThingSpeak fields | Actuators respond appropriately to different scenarios | Pass
5 | Test restart functionality | Verify that the Actuator Module restarts if WiFi connection issues persist | Module restarts when WiFi connection issues persist | Pass

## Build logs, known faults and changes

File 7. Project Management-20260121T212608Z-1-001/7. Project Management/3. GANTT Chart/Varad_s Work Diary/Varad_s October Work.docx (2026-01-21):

*Varad's October's Work:*

Sensor interfacing (breadboard) - 3/10/23

L293D understanding and interfacing (Breadboard) - 4/10/23

Sensors and actuators combined and tested on breadboard - 8/10/23

Flowchart - 9/10/23

Making Connections on Wokwi (IoT Simulation) - 12/10/23

Code to interface sensors and actuators on Wokwi (Embedded) (IoT Simulation)-13/10/23

ThingSpeak (Cloud) integration on Wokwi to Read/Send data (IoT Simulation) - 14/10/23

ThingSpeak (Cloud) integration on Wokwi to Write/Receive data (IoT Simulation)-15/10/23

Design Basic UI (Web Development)-16/10/23

Data field integration from the cloud to the webpage (Web Development)-17/10/23

Write HTML, CSS, and JS code to execute cloud link to the background of the page without redirecting (Web Development)-18/10/23

Finish Primary Web UI and simulation testing (Web Development) - 19/10/23

Switching to hardware from Simulation and testing (Hardware) - 20/10/23

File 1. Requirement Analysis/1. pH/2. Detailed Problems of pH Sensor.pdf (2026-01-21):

Detailed Problems of pH Sensor -Varad Chaskar

pH sensors are widely used in various industries and applications to measure the acidity or alkalinity of a solution. However, like any technology, they come with their own set of challenges and problems. Here are some major problems associated with pH sensors:

1. Calibration and Drift: pH sensors require regular calibration to maintain accurate readings. Over time, they can experience drift, where their accuracy deviates from the calibrated values. This necessitates frequent recalibration, which can be time-consuming and costly.
2. Electrode Contamination: The sensing electrode of a pH sensor can become contaminated by the substances it measures, leading to inaccurate readings. The buildup of proteins, oils, or other substances on the electrode surface can interfere with its ability to detect pH accurately.
3. Electrode Fouling: In applications involving dirty or particulate-laden solutions, the electrode surface can become fouled, affecting its response time and accuracy. This requires regular cleaning and maintenance to prevent degradation of the sensor's performance.
4. Chemical Compatibility: pH sensors are designed for specific pH ranges and chemical environments. Using a sensor in a solution that is outside its intended pH range or chemically incompatible can result in sensor damage or inaccurate readings.
5. Temperature Effects: pH readings can be influenced by temperature variations. Many pH sensors come with built-in temperature compensation mechanisms, but inaccurate temperature compensation can lead to measurement errors.
6. Reference Electrode Issues: Many pH sensors use a reference electrode along with the pH-sensitive electrode. The reference electrode can leak electrolyte or become contaminated, affecting the accuracy of the pH measurement.
7. Signal Interference: pH sensors can be susceptible to interference from other ions present in the solution. This can lead to cross-sensitivity and inaccurate readings if the sensor responds to ions other than H+.
8. Response Time: pH sensors might have a slower response time, especially in applications where quick pH changes occur. This lag in response can lead to delayed measurements and inaccurate data.

9. Mechanical Damage: pH sensors, especially those used in harsh environments, can suffer mechanical damage from abrasion, impact, or other physical factors. This can affect the integrity of the sensor's components and lead to inaccurate readings.
10. Sensor Aging: Over time, the materials in the pH sensor can degrade or change, affecting its overall performance and accuracy. This aging process might not be easily predictable and could lead to gradual deterioration of measurement quality.
11. Cost: High-quality pH sensors can be expensive to purchase and maintain. Cheaper sensors might come with compromised accuracy and durability.
12. Complex Maintenance: Proper maintenance of pH sensors requires regular cleaning, calibration, and sometimes electrode replacement. This maintenance process can be complex and time-intensive, particularly for large-scale industrial applications.

Efforts are continuously made to address these problems through advancements in sensor technology, materials, and design. However, it's important to be aware of these challenges when working with pH sensors and to implement proper maintenance and calibration routines to ensure accurate and reliable measurements.

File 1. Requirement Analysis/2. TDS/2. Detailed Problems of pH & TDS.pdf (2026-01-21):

Detailed Problems of pH Sensor -Varad Chaskar

pH sensors are widely used in various industries and applications to measure the acidity or alkalinity of a solution. However, like any technology, they come with their own set of challenges and problems. Here are some major problems associated with pH sensors:

1. Calibration and Drift: pH sensors require regular calibration to maintain accurate readings. Over time, they can experience drift, where their accuracy deviates from the calibrated values. This necessitates frequent recalibration, which can be time-consuming and costly.
2. Electrode Contamination: The sensing electrode of a pH sensor can become contaminated by the substances it measures, leading to inaccurate readings. The buildup of proteins, oils, or other substances on the electrode surface can interfere with its ability to detect pH accurately.
3. Electrode Fouling: In applications involving dirty or particulate-laden solutions, the electrode surface can become fouled, affecting its response time and accuracy. This requires regular cleaning and maintenance to prevent degradation of the sensor's performance.
4. Chemical Compatibility: pH sensors are designed for specific pH ranges and chemical environments. Using a sensor in a solution that is outside its intended pH range or chemically incompatible can result in sensor damage or inaccurate readings.
5. Temperature Effects: pH readings can be influenced by temperature variations. Many pH sensors come with built-in temperature compensation mechanisms, but inaccurate temperature compensation can lead to measurement errors.
6. Reference Electrode Issues: Many pH sensors use a reference electrode along with the pH-sensitive electrode. The reference electrode can leak electrolyte or become contaminated, affecting the accuracy of the pH measurement.
7. Signal Interference: pH sensors can be susceptible to interference from other ions present in the solution. This can lead to cross-sensitivity and inaccurate readings if the sensor responds to ions other than H+.
8. Response Time: pH sensors might have a slower response time, especially in applications where quick pH changes occur. This lag in response can lead to delayed measurements and inaccurate data.

9. Mechanical Damage: pH sensors, especially those used in harsh environments, can suffer mechanical damage from abrasion, impact, or other physical factors. This can affect the integrity of the sensor's components and lead to inaccurate readings.
10. Sensor Aging: Over time, the materials in the pH sensor can degrade or change, affecting its overall performance and accuracy. This aging process might not be easily predictable and could lead to gradual deterioration of measurement quality.
11. Cost: High-quality pH sensors can be expensive to purchase and maintain. Cheaper sensors might come with compromised accuracy and durability.
12. Complex Maintenance: Proper maintenance of pH sensors requires regular cleaning, calibration, and sometimes electrode replacement. This maintenance process can be complex and time-intensive, particularly for large-scale industrial applications.

Efforts are continuously made to address these problems through advancements in sensor technology, materials, and design. However, it's important to be aware of these challenges when working with pH sensors and to implement proper maintenance and calibration routines to ensure accurate and reliable measurements.

Problems with Continuous Monitoring of TDS
- Varad Chaskar

Continuous monitoring of Total Dissolved Solids (TDS) in water is important for assessing water quality and ensuring the suitability of water for various applications. However, there are several challenges and problems associated with continuous TDS monitoring:

1. Sensor Calibration: TDS sensors need regular calibration to ensure accurate measurements. The calibration process can be complex and time-consuming, and improper calibration can lead to inaccurate readings.
2. Sensor Drift: Similar to pH sensors, TDS sensors can experience drift over time, where their readings deviate from calibrated values. This requires frequent recalibration to maintain accuracy.
3. Electrode Fouling: The sensor electrodes can become fouled by particles, organic matter, and minerals present in the water. This fouling can lead to slower response times and inaccurate readings. Regular cleaning is necessary.
4. Temperature Effects : TDS measurements can be influenced by temperature variations, especially if the sensor doesn't have proper temperature compensation mechanisms. Temperature changes can alter the electrical conductivity of the water, leading to incorrect TDS readings.
5. Interference from Other Ions: TDS sensors measure the conductivity of the solution, and the conductivity can be influenced by ions other than dissolved solids. This can lead to interference from ions like calcium, magnesium, and sulfates, affecting the accuracy of TDS measurements.
6. Variability in Ionic Composition: The TDS value doesn't provide information about the specific types of dissolved solids present in water. Variations in the ionic composition of water can lead to different impacts on water quality, making interpretation of TDS readings challenging.
7. Sensor Sensitivity: TDS sensors might not be equally sensitive to all types of dissolved solids. Some sensors might be more responsive to certain ions than others, leading to discrepancies in TDS measurements.
8. Sensor Degradation: Over time, the sensor's electrodes and components can degrade due to chemical interactions with the water or fouling. This degradation can lead to reduced sensor performance and accuracy.

9. Cost and Maintenance: High-quality TDS sensors can be expensive to purchase and maintain. Routine maintenance, calibration solutions, and replacement parts can add to the overall cost of continuous monitoring.
10. Sensor Complexity: Some TDS sensors might require specialized technical knowledge for installation, calibration, and maintenance. This complexity can pose challenges for users who are not familiar with the technology.
11. Sampling Method: In continuous monitoring systems, the way water is sampled and brought into contact with the sensor can impact measurement accuracy. Improper sampling methods can lead to inaccuracies in TDS readings.
12. Data Interpretation: TDS readings need to be interpreted in the context of the specific application and regulatory guidelines. Understanding the significance of TDS levels and taking appropriate actions based on the readings can be complex.

Despite these challenges, continuous TDS monitoring plays a crucial role in maintaining water quality standards. To mitigate these problems, it's important to choose reliable sensors, follow proper calibration and maintenance procedures, and consider complementary measurements and water quality parameters to gain a comprehensive understanding of water quality.

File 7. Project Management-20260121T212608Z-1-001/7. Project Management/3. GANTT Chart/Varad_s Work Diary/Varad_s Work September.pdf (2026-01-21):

Details of Varad’s Work:

Saturday, 16 September 2023: @Varad Chaskar
- Started a discussion regarding power supply and presented the good and bad sides of power supply.
- Started discussion regarding the procurement of L293D.
- Procured and sent the invoice to Sahaj to create an expense report.
- Presented points to decide on whether to use ESP 32 or ATmega328.
- Sent a rough schematic diagram for Sahaj's reference on his request.
- Sent block diagram description to the group.

Sunday, 17 September 2023: @Varad Chaskar
- Updated the Bill of Materials a little bit.
- Suggested that we should look for ways to reduce the cost of UV light.
- Also, suggested that we should look for cheaper alternatives for the actuators like the air pump, water pump, fan, etc. To make the project more affordable or document the cheaper alternatives.

Monday, 18 September 2023: @Varad Chaskar
- Started the discussion and stated my problem with bringing the whole setup of 2 stacks of hydroponics systems into the college.
- Looked at what a scaled model looks like and stated the problem of a costlier system.

Wednesday, 20 September 2023: @Varad Chaskar
- Read the guidelines of the Aviskar project competition and suggested taking guidelines regarding it from the project guide.
- Learned M2M using ESP 01, stated its advantages and how can it be done and asked to procure ESP 01.
- Requested the expense report, simulation, work done on research paper till today, and documentation of work we have done from the 16 September to Sahaj.

Thursday, 21 September 2023: @Varad Chaskar
- Requested Sahaj to ask the structure of PPT and Report to guide.
- Requested Sahaj to ask some questions to clarify my doubts regarding the Poster and PPT.
- Sent previous year's documents to Sahaj on his request.
- Documented all the innovativeness in the project proposal.
- Updated some objectives and added UPS, M2M, and web design points.

Friday, 22 September 2023: @Varad Chaskar
- Created PPT for Aviskar competition. and added some points to it
- Written "features added due to automation" in a slide.

Saturday, 23 September 2023: @Varad Chaskar
- Took 1 minute of a presentation video for the Aviskar Competition.

Sunday, 24 September 2023: @Varad Chaskar
- Started a discussion on whether we had shown the simulation to the guide and what was causing so much delay.
- Reminded Sahaj to send me the simulation done on the Tinkercad.
- Presented and discussed the Cheaper online option for neopixel lights. (1m 400 rs)
- Got assurance from Sahaj that he will look for a cheaper alternative to the neopixel light from the shop at cheaper prices.

Tuesday, 26 September 2023: @Varad Chaskar
- Checked Tinkercad completed simulation
- Started discussion on the problems of proteus software and our requirements with the simulation.
- Started discussion about the offline prices of neopixel lights.
- Presented the cheaper available option for a peristaltic water pump as per the requirement.
- Requested Sahaj to create an expense report for my purchase. and discussed what's causing so much delay.

Wednesday, 27 September 2023: @Varad Chaskar
- Asked whether we really needed to create two two-stack systems and presented the problems on it.
- Proposed my problem of not having neopixel lights, causing a delay in the breadboard testing.
- Explained to Sahaj what our previous grow lights consisted of.
- Illustrated why neopixel lights are better.

Thursday, 28 September 2023: @Varad Chaskar
- Started discussion on how to test L293D separately.

Friday, 29 September 2023: @Varad Chaskar
- Started discussion for the Status of the Review Paper and What's causing so much delay.

Saturday, 30 September 2023: @Varad Chaskar
- Stated that I need the expense report for L293D and the documentation of our work urgently.
- Illustrated how an RGB light requires more GPIO pins than neopixel lights.

Please note that to support all the above, I have evidence of WhatsApp messages, call recordings, voice recordings, etc.

Thanks and Regards,
Varad Chaskar

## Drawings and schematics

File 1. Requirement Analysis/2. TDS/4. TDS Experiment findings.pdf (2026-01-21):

## 0 TDS, 100 TDS, 200 TDS, 300 TDS, 400 TDS…

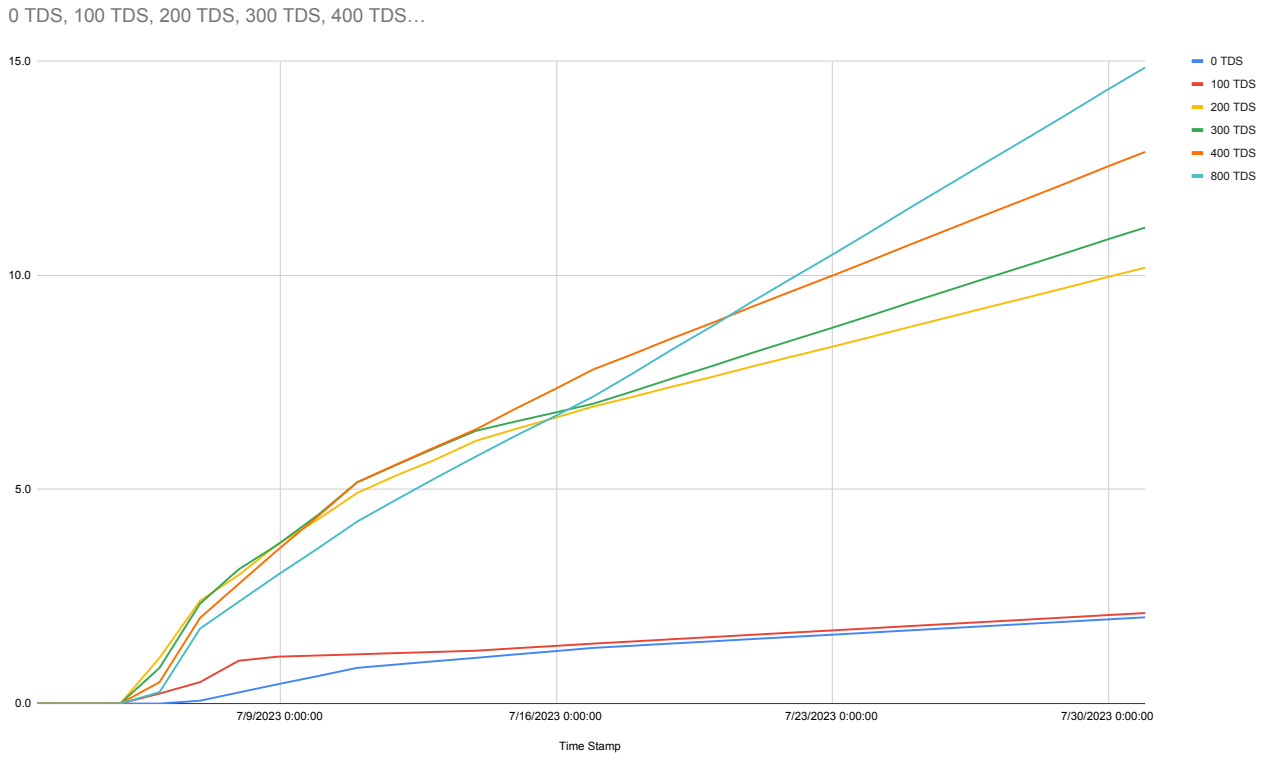
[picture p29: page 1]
Time Stamp; 0 TDS; 100 TDS; 200 TDS; 300 TDS; 400 TDS; 800 TDS

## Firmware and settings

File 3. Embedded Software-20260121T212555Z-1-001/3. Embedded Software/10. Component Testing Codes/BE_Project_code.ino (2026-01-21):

#include <Adafruit_Sensor.h>
#include <DHT.h>
#include <DHT_U.h>
#include <Wire.h>
#include <RTClib.h>
#include <FirebaseESP32.h>

// Firebase configuration
//#define FIREBASE_HOST ""
//#define FIREBASE_AUTH ""
//#define FIREBASE_PATH ""

// Define pins for DHT11, L293D, LEDs, and water pump
#define DHT_PIN 2
#define FAN_ENABLE 
#define RED_LED 5
#define BLUE_LED 6
#define AIR_PUMP_ENABLE 2
#define WATER_LEVEL_SENSOR 5
#define WATER_PUMP_ENABLE 18

// Define constants
#define DHT_TYPE DHT11
#define WATER_LEVEL_THRESHOLD 500 //Half
#define FAN_SPEED_INCREASE 255 // Maximum speed

RTC_DS3231 rtc;
DHT_Unified dht(DHT_PIN, DHT_TYPE);
FirebaseData firebaseData;

void setup() {
  // Initialize serial communication
  Serial.begin(115200);

  // Initialize sensors
  dht.begin();
  Wire.begin();
  rtc.begin();


  // Set pin modes
  pinMode(FAN_ENABLE, OUTPUT);
  pinMode(RED_LED, OUTPUT);
  pinMode(BLUE_LED, OUTPUT);
  pinMode(AIR_PUMP_ENABLE, OUTPUT);
  pinMode(WATER_PUMP_ENABLE, OUTPUT);

  // Initialize Firebase
//  Firebase.begin(FIREBASE_HOST, FIREBASE_AUTH);
}

void loop() {
  DateTime now = rtc.now();
  float temperature = readTemperature();

  // Turn on fan if temperature increases
  if (temperature > 25.0) {
    increaseFanSpeed();
  } else {
    decreaseFanSpeed();
  }

  // Control lights based on time
  if (now.hour() >= 8 && now.hour() < 20) {
    turnOnLights();
  } else {
    turnOffLights();
  }

  // Control air pump based on time
  if ((now.hour() >= 7 && now.hour() < 8) || (now.hour() >= 20 && now.hour() < 21)) {
    turnOnAirPump();
  } else {
    turnOffAirPump();
  }

  // Check water level and control water pump
  int waterLevel = analogRead(WATER_LEVEL_SENSOR);
  if (waterLevel < WATER_LEVEL_THRESHOLD) {
    turnOnWaterPump();
  } else {
    turnOffWaterPump();
  }

  // Bluetooth control
  if (Serial.available() >= 2) {
    char command = Serial.read();
    if (command == 'A' || command == 'a') {
      // Control Appliance A (Fan)
      toggleFan();
    } else if (command == 'B' || command == 'b') {
      // Control Appliance B (Air Pump)
      toggleAirPump();
    }
  }

  // Send data to Firebase
//  sendDataToFirebase(temperature, waterLevel);

  delay(1000); // Update every second
}

float readTemperature() {
  sensors_event_t event;
  dht.temperature().getEvent(&event);
  if (!isnan(event.temperature)) {
    return event.temperature;
  } else {
    return 0.0;
  }
}

void increaseFanSpeed() {
  analogWrite(FAN_ENABLE, FAN_SPEED_INCREASE);
}

void decreaseFanSpeed() {
  analogWrite(FAN_ENABLE, 0);
}

void turnOnLights() {
  digitalWrite(RED_LED, HIGH);
  digitalWrite(BLUE_LED, HIGH);
}

void turnOffLights() {
  digitalWrite(RED_LED, LOW);
  digitalWrite(BLUE_LED, LOW);
}

void turnOnAirPump() {
  digitalWrite(AIR_PUMP_ENABLE, HIGH);
}

void turnOffAirPump() {
  digitalWrite(AIR_PUMP_ENABLE, LOW);
}

void turnOnWaterPump() {
  digitalWrite(WATER_PUMP_ENABLE, HIGH);
}

void turnOffWaterPump() {
  digitalWrite(WATER_PUMP_ENABLE, LOW);
}

void toggleFan() {
  if (analogRead(FAN_ENABLE) == 0) {
    increaseFanSpeed();
  } else {
    decreaseFanSpeed();
  }
}

void toggleAirPump() {
  if (digitalRead(AIR_PUMP_ENABLE) == LOW) {
    turnOnAirPump();
  } else {
    turnOffAirPump();
  }
}

//void sendDataToFirebase(float temperature, int waterLevel) {
  // Build the data JSON object
  //String data = "{";
  //data += "\"temperature\":" + String(temperature) + ",";
  //data += "\"water_level\":" + String(waterLevel);
  //data += "}";

  // Send data to Firebase
  //Firebase.pushString(firebaseData, FIREBASE_PATH, data);
}

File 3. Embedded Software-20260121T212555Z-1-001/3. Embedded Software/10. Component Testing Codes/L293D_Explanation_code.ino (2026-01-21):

// L293D Motor Speed and Direction Control with Arduino

// Define the pins connected to the L293D
int enablePin = 5;   // Enable pin (EN) connected to Arduino digital pin 9
int in1Pin = 18;      // Input 1 (IN1) connected to Arduino digital pin 8
int in2Pin = 19;      // Input 2 (IN2) connected to Arduino digital pin 7

void setup() {
  // Define the motor control pins as outputs
  pinMode(enablePin, OUTPUT);
  pinMode(in1Pin, OUTPUT);
  pinMode(in2Pin, OUTPUT);
  
  // Initialize the motor to be off (no movement)
  digitalWrite(enablePin, LOW);
  digitalWrite(in1Pin, LOW);
  digitalWrite(in2Pin, LOW);
}

void loop() {
  // Move the motor forward at gradually increasing speed
  motorForward();
  for (int speed = 0; speed <= 255; speed++) {
    analogWrite(enablePin, speed);
    delay(10);
  }
  delay(1000); // Wait for 1 second at full speed
  
  // Move the motor backward at gradually increasing speed
  motorBackward();
  for (int speed = 0; speed <= 255; speed++) {
    analogWrite(enablePin, speed);
    delay(10);
  }
  delay(1000); // Wait for 1 second at full speed
  
  // Stop the motor
  motorStop();
  delay(1000); // Wait for 1 second at stopped position
}

void motorForward() {
  digitalWrite(in1Pin, HIGH);
  digitalWrite(in2Pin, LOW);
}

void motorBackward() {
  digitalWrite(in1Pin, LOW);
  digitalWrite(in2Pin, HIGH);
}

void motorStop() {
  digitalWrite(in1Pin, LOW);
  digitalWrite(in2Pin, LOW);
  analogWrite(enablePin, 0); // Set speed to 0 to stop the motor
}

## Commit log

2026-01-21 Add Hardware phase documents
    [10-Pin Header - Female - 2.54mm.step, 11-Pin Header - Female - 2.54mm.step, 12-Pin Header - Female - 2.54mm.step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]
2026-01-21 Add remaining project phases
    [Work Breakdown Structure of ASAA MK-II.xlsx]
